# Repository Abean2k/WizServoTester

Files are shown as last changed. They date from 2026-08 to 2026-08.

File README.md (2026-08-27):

# WizServoTester



A servo controller PCB that can control up to 4 servos using onboard rotary encoders. Powered by an ESP32-C6 with two power input modes, USB and FTC 12V Battery. 

## Design and Inspo:
I wanted to solve the issue that my team and many other FTC teams I know have. When testing Gobiulda Servos (such as during Robot In 3 Days) we need a fast way to move multiple servos without using code. 
Currently, the only solution available is from Gobiulda, and the full kit for 4 servos cost about $200. So, I made WizServotester!

When designing this I made sure to keep it useful to FTC teams by allowing teams to use their existing battery to power the device. Teams already have many 12v 10 cell batteries, so I have included the xt30 connector that all these batteries have and a buck converter to step the voltage down to 5v for use in the circuit. The entire thing can be reprogrammed using the USBc and inbuilt USB programmer on the ESP32-C6. 

### Power:
This thing can be powered in two ways - USB & Battery. When under battery power all 4 servos can be used at full load and in both continuous and normal modes. However, when in USB power, only 1 servo can be used at one time. This is due to the limited power capacity of a USB C cable. Power can be selected using a switch on the pcb.  

## PCB:
I made a 2 layered PCB on Kicad for the servo tester. The pcb is around 100mm by 60mm. I have included some instructions on how to use the power switch and battery connector as well as some PCB Art (my first time trying that out <3). 

### Schematic


### PCB Layout


## Case:
This is optional, if you are recreating this project, you can choose to use my case or just not use a case. Made with two parts, a base, and a top cover type thing. Uses m3 screws to fasten the PCB into the case and the bottom of the base to the top. Designed on Onshape. 



## Firmware:
The ESP32 will run C++ with Arduino. The code is still under development. The idea is that the code can detect the voltage of the USDB to see where it's receiving power from, then it can control the servos based on the position of the rotary encoder. Lots of the code is similar to my rocketry airbrake project so V1 code development was quick. The online app that is hosted on the ESP will be added based on how the PCB performs and feedback I receive from my team about the tester. 

## Bill of Materials (BOM)

| Part | Quantity | Retailer | Total Price |
|---|---|---|---|
| ESP32-C6-WROOM-1 | 1x5 | LCSC | $21.16 |
| SMD Caps (10u, 100n, 1u, 22u) | 9 x 5 | Already have | $0.00 |
| 470u 16v Capacitor | 1x5 | LCSC | $0.61 |
| ESD9B3.3 Diode | 2x5 | LCSC | $0.53 |
| SS34 Schottky Diode | 1x5 | LCSC | $0.71 |
| SS54 Schottky Diode | 1x5 | LCSC | $0.45 |
| USB-C Receptacle | 1x5 | LCSC | $0.62 |
| XT30 Battery Connector | 1x5 | AliExpress | $2.97 |
| (01x03) Male 90 Degree Header | 4x5 | AliExpress | $5.58 |
| Resistors (10k, 5.1k, 4.7k) | 30 | Already have | $0.00 |
| EC11 Rotary Encoder | 4x5 | AliExpress | $3.24 |
| Push Button Switch | 2x5 | LCSC | $0.53 |
| SPDT Power Select Switch ($1.84) | 1x5 | LCSC | $1.84 |
| USBLC6-2SC6 (USB Protection) | 1x5 | LCSC | $0.48 |
| AMS1117-3.3 (LDO) | 1x5 | LCSC | $0.49 |
| Mini560 Buck Converter | 1x5 | AliExpress | $4.40 |
| PCB (5x boards) | 1x5 | LCSC | $11.32 |

**Taxes & Shipping: AliExpress ($0.96) + LCSC ($10.80)** 

**Total Cost For 5 PCBS: $66.69**

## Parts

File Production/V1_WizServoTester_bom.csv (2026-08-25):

Designator | Footprint | Quantity | Value | LCSC Part #
C1 | 0805 | 1 | 10u
C2, C4 | 0805 | 2 | 100n
C3 | 0805 | 1 | 1u
C5, C6, C7, C9 | 0805 | 4 | 22u
C8 | CP_Elec_8x10.5 | 1 | 470u 16v
D2 | D_SMA | 1 | SS34
D4 | D_SMA | 1 | SS54
J1 | USB_C_Receptacle_HCTL_HC-TYPE-C-16P-01A | 1 | USB_C_Receptacle_USB2.0_16P
J2 | PinHeader_1x03_P2.54mm_Horizontal | 1 | Servo_3_Header
J3 | PinHeader_1x03_P2.54mm_Horizontal | 1 | Servo_4_Header
J4 | PinHeader_1x03_P2.54mm_Horizontal | 1 | Servo_1_Header
J5 | PinHeader_1x03_P2.54mm_Horizontal | 1 | Servo_2_Header
J6 | AMASS_XT30U-F_1x02_P5.0mm_Vertical | 1 | BAT_XT30
J8 | TestPoint_2Pads_Pitch5.08mm_Drill1.3mm | 1 | BAT_Pads
R1, R4, R6 | 0805 | 3 | 10k
R2, R3 | 0805 | 2 | 5.1k
R5 | 0805 | 1 | 4.7k
SW1, SW2, SW3, SW4 | RotaryEncoder_Alps_EC11E-Switch_Vertical_H20mm_MountingHoles | 4 | EC 11
SW5, SW7 | SW_SPST_TS-1088-xR020 | 2 | SW_Push
SW6 | SW-TH_XKB_SS-12M11XX | 1 | SW_SPDT | C2879832
U1 | ESP32-C6-WROOM-1 | 1 | ESP32-C6-WROOM-1
U2 | SOT-23-6 | 1 | USBLC6-2SC6
U3 | SOT-223-3_TabPin2 | 1 | AMS1117-3.3
U4 | mini650 | 1 | Mini560

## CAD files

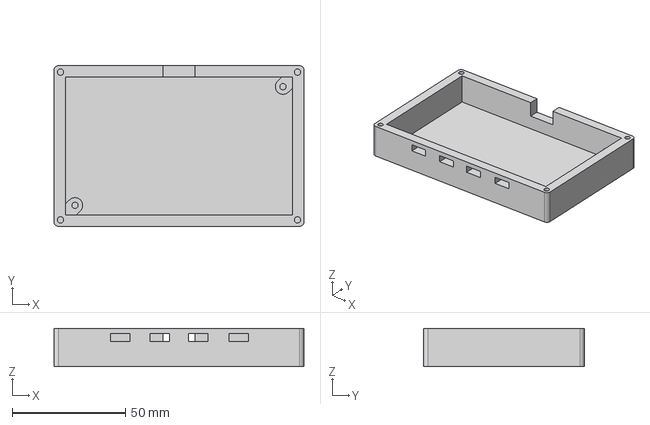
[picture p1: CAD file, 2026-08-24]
Case/Case Main.step
110.6 x 71.1 x 17.0 mm

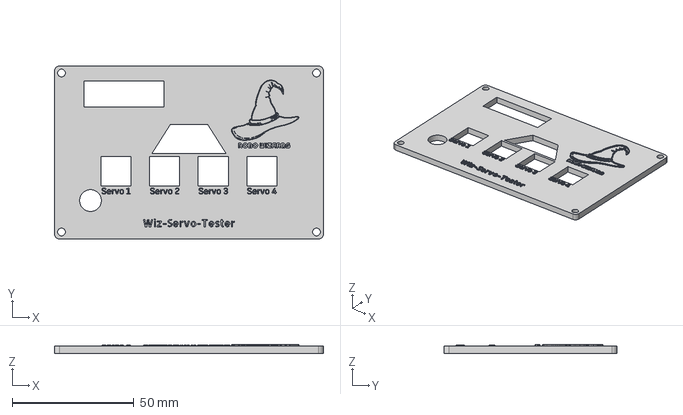
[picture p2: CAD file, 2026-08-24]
Case/Case (Top).step
110.6 x 71.1 x 3.53 mm

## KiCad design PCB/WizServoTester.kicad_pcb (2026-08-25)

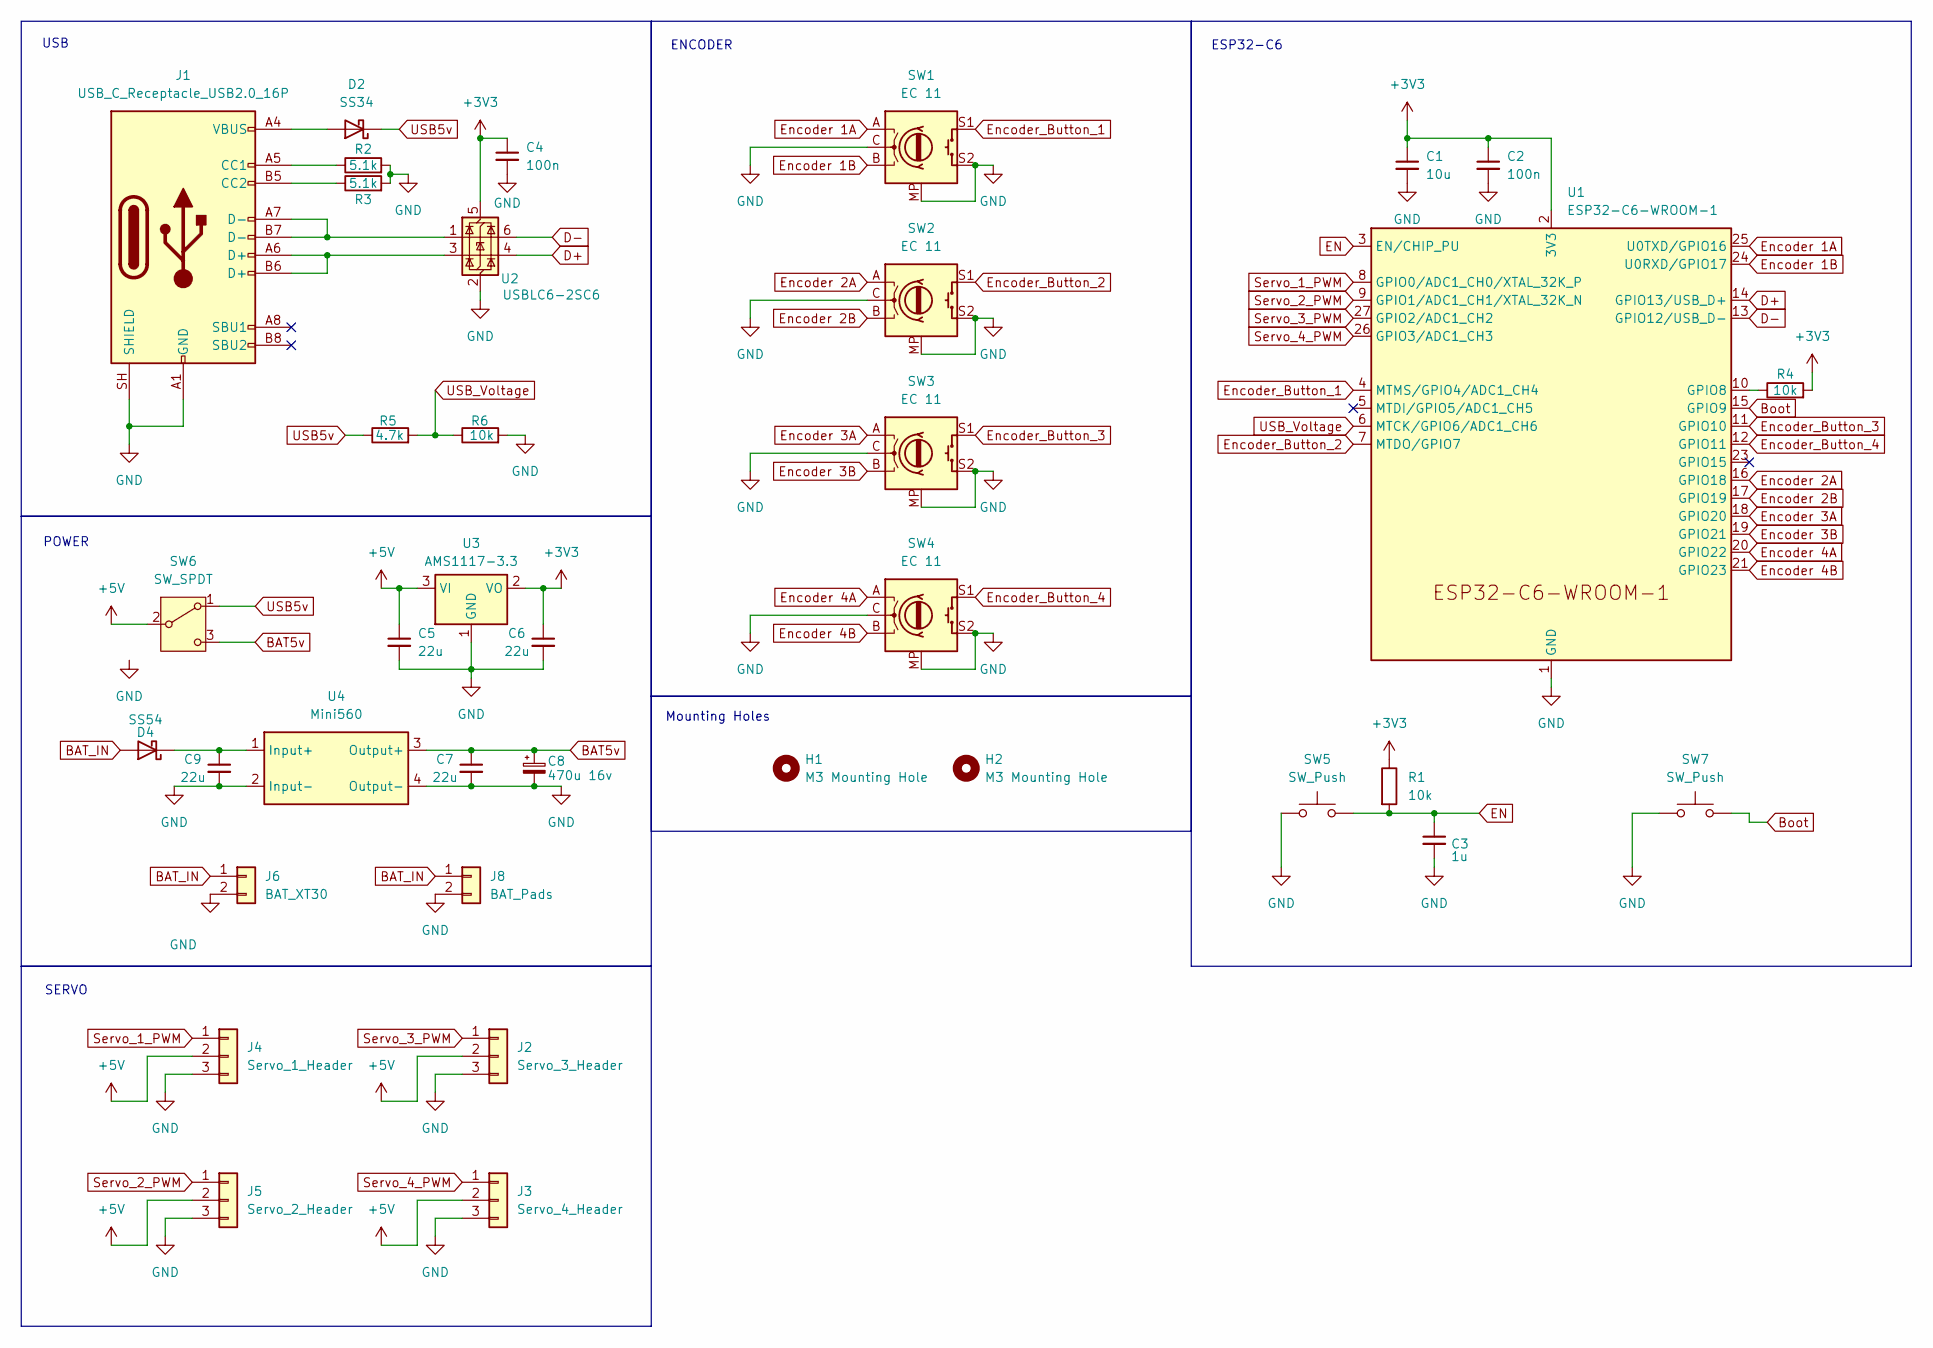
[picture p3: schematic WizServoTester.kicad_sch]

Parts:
C1: 10u; C_0805_2012Metric
C2, C4: 100n; C_0805_2012Metric
C3: 1u; C_0805_2012Metric
C5, C6, C7, C9: 22u; C_0805_2012Metric
C8: 470u 16v; CP_Elec_8x10.5
D2: SS34; D_SMA
D4: SS54; D_SMA
H1, H2: M3 Mounting Hole; MountingHole_3.2mm_M3
J1: USB_C_Receptacle_USB2.0_16P; USB_C_Receptacle_HCTL_HC-TYPE-C-16P-01A
J2: Servo_3_Header; PinHeader_1x03_P2.54mm_Horizontal
J3: Servo_4_Header; PinHeader_1x03_P2.54mm_Horizontal
J4: Servo_1_Header; PinHeader_1x03_P2.54mm_Horizontal
J5: Servo_2_Header; PinHeader_1x03_P2.54mm_Horizontal
J6: BAT_XT30; AMASS_XT30U-F_1x02_P5.0mm_Vertical
J8: BAT_Pads; TestPoint_2Pads_Pitch5.08mm_Drill1.3mm
R1, R4, R6: 10k; R_0805_2012Metric
R2, R3: 5.1k; R_0805_2012Metric
R5: 4.7k; R_0805_2012Metric
SW1, SW2, SW3, SW4: EC 11; RotaryEncoder_Alps_EC11E-Switch_Vertical_H20mm_MountingHoles
SW5, SW7: SW_Push; SW_SPST_TS-1088-xR020
SW6: SW_SPDT; SW-TH_XKB_SS-12M11XX
U1: ESP32-C6-WROOM-1
U2: USBLC6-2SC6; SOT-23-6
U3: AMS1117-3.3; SOT-223-3_TabPin2
U4: Mini560; mini650

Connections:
+3V3: C1.1, C2.1, C4.1, C6.1, R1.1, R4.2, U1.2 (3V3), U2.5 (VBUS), U3.2 (VO)
+5V: C5.1, J2.2, J3.2, J4.2, J5.2, SW6.2 (B), U3.3 (VI)
BAT5v: C7.1, C8.1, SW6.3 (C), U4.3 (Output+)
BAT_IN: D4.2 (A), J6.1, J8.1
Boot: SW7.2, U1.15 (GPIO9)
D+: U1.14 (GPIO13/USB_D+), U2.4 (I/O2)
D-: U1.13 (GPIO12/USB_D-), U2.6 (I/O1)
EN: C3.1, R1.2, SW5.2, U1.3 (EN/CHIP_PU)
Encoder 1A: SW1.A, U1.25 (U0TXD/GPIO16)
Encoder 1B: SW1.B, U1.24 (U0RXD/GPIO17)
Encoder 2A: SW2.A, U1.16 (GPIO18)
Encoder 2B: SW2.B, U1.17 (GPIO19)
Encoder 3A: SW3.A, U1.18 (GPIO20)
Encoder 3B: SW3.B, U1.19 (GPIO21)
Encoder 4A: SW4.A, U1.20 (GPIO22)
Encoder 4B: SW4.B, U1.21 (GPIO23)
Encoder_Button_1: SW1.S1, U1.4 (MTMS/GPIO4/ADC1_CH4)
Encoder_Button_2: SW2.S1, U1.7 (MTDO/GPIO7)
Encoder_Button_3: SW3.S1, U1.11 (GPIO10)
Encoder_Button_4: SW4.S1, U1.12 (GPIO11)
GND: C1.2, C2.2, C3.2, C4.2, C5.2, C6.2, C7.2, C8.2, C9.2, J1.A1 (GND), J1.A12 (GND), J1.B1 (GND), J1.B12 (GND), J1.SH (SHIELD), J2.3, J3.3, J4.3, J5.3, J6.2, J8.2, R2.2, R3.2, R6.2, SW1.C, SW1.MP, SW1.S2, SW2.C, SW2.MP, SW2.S2, SW3.C, SW3.MP, SW3.S2, SW4.C, SW4.MP, SW4.S2, SW5.1, SW7.1, U1.1 (GND), U1.28 (GND), U1.29 (GND), U2.2 (GND), U3.1 (GND), U4.2 (Input-), U4.4 (Output-)
unnamed: D2.2 (A), J1.A4 (VBUS), J1.A9 (VBUS), J1.B4 (VBUS), J1.B9 (VBUS)
unnamed: C9.1, D4.1 (K), U4.1 (Input+)
unnamed: J1.A5 (CC1), R2.1
unnamed: J1.B5 (CC2), R3.1
unnamed: J1.A6 (D+), J1.B6 (D+), U2.3 (I/O2)
unnamed: J1.A7 (D-), J1.B7 (D-), U2.1 (I/O1)
unnamed: R4.1, U1.10 (GPIO8)
Servo_1_PWM: J4.1, U1.8 (GPIO0/ADC1_CH0/XTAL_32K_P)
Servo_2_PWM: J5.1, U1.9 (GPIO1/ADC1_CH1/XTAL_32K_N)
Servo_3_PWM: J2.1, U1.27 (GPIO2/ADC1_CH2)
Servo_4_PWM: J3.1, U1.26 (GPIO3/ADC1_CH3)
USB5v: D2.1 (K), R5.1, SW6.1 (A)
USB_Voltage: R5.2, R6.1, U1.6 (MTCK/GPIO6/ADC1_CH6)

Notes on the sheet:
ESP32-C6
ENCODER
POWER
USB
SERVO
Mounting Holes

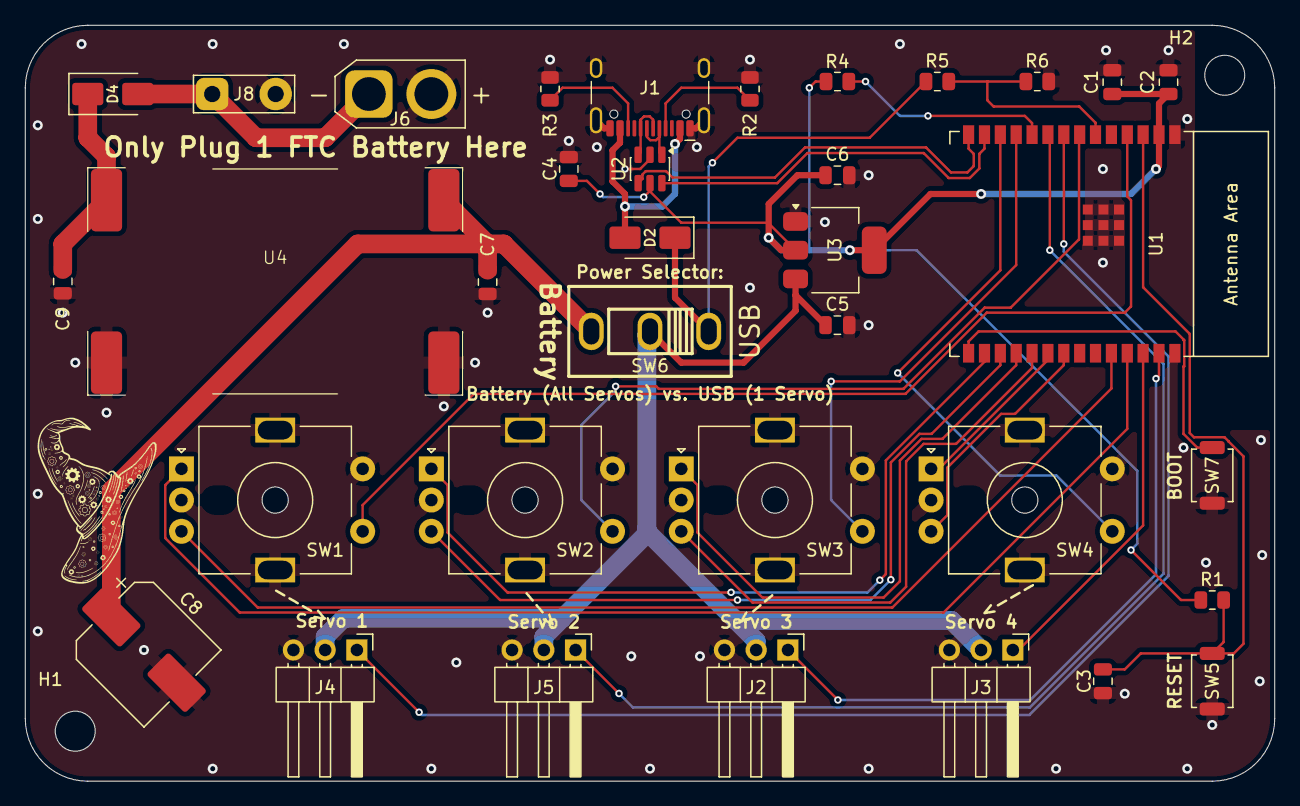
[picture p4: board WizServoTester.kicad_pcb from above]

Board: 2 copper layers, 100.0 x 60.5 mm, 37 parts (0 on the bottom side), 34 nets.

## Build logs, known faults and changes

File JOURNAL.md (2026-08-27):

---
Title: WizServotester
Github: (https://github.com/Abean2k/WizServoTester)
Description: 4-channel servo tester for FTC
Created_at: "2026-08-19"
Total Time Spent: ~16.5 Hours
---

# August 21 & August 20: <Schematic Finished>

This project is one that me, my team, and many other FTC teams I know could use and would love to have. 

***Here is the issue:*** When testing Gobiulda servos, their servo testing kit is either very expensive ($200+) and/or not compatible with the FTC batteries and all four servos. 

To solve this before Robot In 3 Days and make something that I think other robotics people might want I started working on this 4-channel servo tester. 
I wanted this to be very frictionless while we (and others) are using it. So, I decided to use the Esp32 family for my MCU, and eventually chose the C6 due to the price, GPIO pins, and ease of use. 
For control I will be having 4 encoders (one for each servo) with buttons for switching servo modes. 
For power, the tester can power one servo when connected to USB power and all 4 at the same time when connected to the battery.
To increase the usefulness for more FTC teams I am also including multiple BAT connection ports (Xt60, Powerpole, and Pads). 

Today I spent my time reading the ESP32-C6-Wroom-1 Data Sheet to see how I should set up the boot pins, where I can route each servo and encoder, etc. 
After that I started making my schematic and was able to finish it just after 12AM lol...

**Here is my Schematic:**


**Total time spent: 6h**

# August 22: <PCB Routing Finished>

Today I worked on assigning all the footprints to their respective schematics. 

While doing so I also had to make a footprint for the AliExpress buck converter thing, here was the picture of that:


After arraigning everything inside of a 100mm x 60mm pcb I routed everything. Making sure to use thick traces for the power traces. I also added the team logo at the front in the little free space.

**Total time spent: 3h**

**Here is my PCB:**


# August 23: <PCB Fixes and Case>

So today, I did a few things. Starting off, I fixed the ground planes. Before, I only had one ground plane, and the top copper plane was just a no net pad. Now, I changed both of them to ground pads and connected them with stitching vias spaced about every 15mm and I also added vias next to the doubling caps and large power gnd returns.  I also added some more logos and silkscreen stuff on the back. 

**Here are pictures of the improved pcb:**






I also made a case for the servo tester on Onshape:


**Total time spent: 4h**

# August 24: <Code and Documentation>
Today I worked on getting the project finished. I worked on the code for the servo tester. For now is to detect the voltage of the USDB to see where it's receiving power from, then it can control the servos based on the position of the rotary encoder. Many of the functions and stuff are similar to my rocketry airbrake project so the version one development of the code was quick. Once I get the servo tester made, I plan on adding more features to the code :)

I also made fixed the readme and BOM. Here are pictures of that:




**Total time spent: 3h**

# August 26: <Last PCB Fixes>
I got some suggestions to change my pcb to remove the unneeded esd diodes, and also move the large 470uF capacitor from the main 5v line to only the battery power line. 

I learned that the usb cannot have more than 10uF capacitance on it's main power rail, as that will draw way to much current from something like a computer port at startup. 

Anyway, here is the updated schematic:


**Total time spent: 0.5h**

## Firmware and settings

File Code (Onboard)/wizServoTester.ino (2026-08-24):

#include <ESP32Servo.h>

// Servo PWM pins
const int SERVO_PINS[4] = {0, 1, 2, 3};

// Rotary Encoder pins (A, B, Button)
const int ENCODER_A[4] = {16, 18, 20, 22};
const int ENCODER_B[4] = {17, 19, 21, 23};  
const int ENCODER_BUTTON[4] = {4, 7, 10, 11};

// USB Power detection (ADC pin reading USB voltage divider)
const int USB_DETECT_PIN = ADC1_CHANNEL_4; 
const int USB_THRESHOLD = 1500;  // ADC threshold for USB detection (adjust when i get pcb)

// Servo control
Servo servos[4];
const int SERVO_MIN = 1000;    // 0° position (µs)    TODO: Change based on gobiulda servo... each one is different 
const int SERVO_MAX = 2000;    // 300° position (µs)  TODO: Change based on gobiulda servo... each one is different 
const int SERVO_CENTER = 1500; // Center for continuous rotation

// Servo state (did it this way to keep it organized)
struct ServoState {
  int currentAngle;           // Current position (0-300)
  int targetAngle;            // Target position
  bool isContinuous;          // true = continuous rotation, false = normal servo
  bool isMoving;              // Currently moving to target
  int continuousSpeed;        // Speed for continuous mode (-100 to 100)
  unsigned long lastUpdate;   // For smooth movement timing
};

ServoState servoState[4] = {
  {150, 150, false, false, 0, 0},
  {150, 150, false, false, 0, 0},
  {150, 150, false, false, 0, 0},
  {150, 150, false, false, 0, 0}
};

// Encoder State
struct EncoderState {
  int lastA;
  int lastB;
  int position;  // 0-255 for servo angle mapping
  unsigned long lastButtonPress;
};

EncoderState encoderState[4] = {
  {0, 0, 128, 0},
  {0, 0, 128, 0},
  {0, 0, 128, 0},
  {0, 0, 128, 0}
};

// Power State
bool isUSBPowered = false;
int lastActiveServo = -1;  // Track which servo is currently moving (USB mode)


void setup() {
  Serial.begin(115200);
  delay(1000);
  
  Serial.println("Servo Tester Initializing...");
  
  // Setup servos
  for (int i = 0; i < 4; i++) {
    servos[i].setPeriodHertz(50);  // Standard servo frequency
    servos[i].attach(SERVO_PINS[i], SERVO_MIN, SERVO_MAX);
    servos[i].write(150);  // Center all servos
  }
  
  // Setup encoder pins
  for (int i = 0; i < 4; i++) {
    pinMode(ENCODER_A[i], INPUT_PULLUP);
    pinMode(ENCODER_B[i], INPUT_PULLUP);
    pinMode(ENCODER_BUTTON[i], INPUT_PULLUP);
    encoderState[i].lastA = digitalRead(ENCODER_A[i]);
    encoderState[i].lastB = digitalRead(ENCODER_B[i]);
  }
  
  // Setup USB detection ADC
  analogReadResolution(12);  // 12-bit resolution (0-4095)
  
  Serial.println("Setup complete!");
}

void loop() {
  // Check USB power status
  updateUSBPowerStatus();
  
  // Read all encoders
  for (int i = 0; i < 4; i++) {
    updateEncoder(i);
    updateEncoderButton(i);
  }
  
  // Update servo positions based on power mode
  if (isUSBPowered) {
    updateServosUSBMode();
  } else {
    updateServosBatteryMode();
  }
  
  // Print status (will disable when done with testing)
  static unsigned long lastPrint = 0;
  if (millis() - lastPrint > 500) {
    printStatus();
    lastPrint = millis();
  }
  
  delay(20);  // 50Hz update rate
}


void updateUSBPowerStatus() {
  int adcValue = analogRead(USB_DETECT_PIN);
  isUSBPowered = (adcValue > USB_THRESHOLD);
  
  // When switching modes, stop all servos
  static bool lastUSBState = false;
  if (isUSBPowered != lastUSBState) {
    Serial.print("Power mode changed to: ");
    Serial.println(isUSBPowered ? "USB" : "Battery");
    lastUSBState = isUSBPowered;
  }
}


void updateEncoder(int encoderNum) {
  int currentA = digitalRead(ENCODER_A[encoderNum]);
  int currentB = digitalRead(ENCODER_B[encoderNum]);
  
  // Detect rotation (quadrature encoding)
  if (currentA != encoderState[encoderNum].lastA) {
    if (currentA == currentB) {
      // Clockwise
      encoderState[encoderNum].position = constrain(
        encoderState[encoderNum].position + 5, 0, 255
      );
    } else {
      // Counter-clockwise
      encoderState[encoderNum].position = constrain(
        encoderState[encoderNum].position - 5, 0, 255
      );
    }
  }
  
  encoderState[encoderNum].lastA = currentA;
  encoderState[encoderNum].lastB = currentB;
  
  // Map encoder position (0-255) to servo angle (0-300)
  int newAngle = map(encoderState[encoderNum].position, 0, 255, 0, 300);
  
  // For normal servo mode, update target angle
  if (!servoState[encoderNum].isContinuous) {
    servoState[encoderNum].targetAngle = newAngle;
  } else {
    // For continuous mode, map to speed (-100 to 100)
    servoState[encoderNum].continuousSpeed = map(newAngle, 0, 180, -100, 100);
  }
}

void updateEncoderButton(int encoderNum) {
  if (digitalRead(ENCODER_BUTTON[encoderNum]) == LOW) {
    unsigned long now = millis();
    
    // Debounce: only register press if >200ms since last press
    if (now - encoderState[encoderNum].lastButtonPress > 200) {
      // Toggle mode
      servoState[encoderNum].isContinuous = !servoState[encoderNum].isContinuous;
      
      Serial.print("Servo ");
      Serial.print(encoderNum);
      Serial.print(" switched to ");
      Serial.println(servoState[encoderNum].isContinuous ? "Continuous" : "Normal");
      
      // Reset servo to neutral on mode switch
      if (servoState[encoderNum].isContinuous) {
        servoState[encoderNum].continuousSpeed = 0;
      } else {
        servoState[encoderNum].targetAngle = 150;
      }
      
      encoderState[encoderNum].lastButtonPress = now;
    }
  }
}

// SERVO CONTROL - USB MODE 
void updateServosUSBMode() {
  // USB mode: only 1 servo at a time
  // Priority: any continuous-mode servo running, else first normal-mode servo needing movement
  
  int servoToMove = -1;
  
  // Check if any continuous servo is running
  for (int i = 0; i < 4; i++) {
    if (servoState[i].isContinuous && servoState[i].continuousSpeed != 0) {
      servoToMove = i;
      break;
    }
  }
  
  // If no continuous servo, find first normal servo that needs movement
  if (servoToMove == -1) {
    for (int i = 0; i < 4; i++) {
      if (!servoState[i].isContinuous && servoState[i].currentAngle != servoState[i].targetAngle) {
        servoToMove = i;
        break;
      }
    }
  }
  
  // Move the selected servo
  for (int i = 0; i < 4; i++) {
    if (i == servoToMove) {
      moveServo(i);
    } else {
      // Stop other servos
      if (servoState[i].isContinuous) {
        servos[i].writeMicroseconds(SERVO_CENTER);  // Stop
      }
    }
  }
}

// ============= SERVO CONTROL - BATTERY MODE =============
void updateServosBatteryMode() {
  // Battery mode: all servos can move simultaneously
  for (int i = 0; i < 4; i++) {
    moveServo(i);
  }
}

// ============= MOVE INDIVIDUAL SERVO =============
void moveServo(int servoNum) {
  ServoState& servo = servoState[servoNum];
  
  if (servo.isContinuous) {
    // Continuous rotation mode
    if (servo.continuousSpeed == 0) {
      // Stop
      servos[servoNum].writeMicroseconds(SERVO_CENTER);
    } else if (servo.continuousSpeed > 0) {
      // Forward: speed 0-100 maps to 1500-2000 µs
      int microseconds = map(servo.continuousSpeed, 0, 100, SERVO_CENTER, SERVO_MAX);
      servos[servoNum].writeMicroseconds(microseconds);
    } else {
      // Reverse: speed -100 to 0 maps to 1000-1500 µs
      int microseconds = map(servo.continuousSpeed, -100, 0, SERVO_MIN, SERVO_CENTER);
      servos[servoNum].writeMicroseconds(microseconds);
    }
  } else {
    // Normal servo mode: smooth movement to target
    int direction = (servo.currentAngle < servo.targetAngle) ? 1 : -1;
    
    if (servo.currentAngle != servo.targetAngle) {
      servo.currentAngle += direction;
      servo.isMoving = true;
    } else {
      servo.isMoving = false;
    }
    
    // Map angle (0-300)
    int microseconds = map(servo.currentAngle, 0, 300, SERVO_MIN, SERVO_MAX);
    servos[servoNum].writeMicroseconds(microseconds);
  }
}

// printing thing (copied from rp2040 rocket thing code)
void printStatus() {
  Serial.print("Power: ");
  Serial.print(isUSBPowered ? "USB" : "Battery");
  Serial.print(" | Servos: ");
  
  for (int i = 0; i < 4; i++) {
    Serial.print("[");
    Serial.print(i);
    Serial.print(":");
    if (servoState[i].isContinuous) {
      Serial.print("C");
      Serial.print(servoState[i].continuousSpeed);
    } else {
      Serial.print("N");
      Serial.print(servoState[i].currentAngle);
    }
    Serial.print("]");
  }
  Serial.println();
}

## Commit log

2026-08-21 Finished Draft of Schematic
    [WizServoTester.kicad_pcb, WizServoTester.kicad_sch]
2026-08-21 Add project journal entry for WizServotester
    Document project details and initial progress on the 4-channel servo tester, including schematic completion and design considerations.
2026-08-22 Update JOURNAL.md with August 22 entry
    Documented progress on PCB routing and footprint assignments.
2026-08-24 Update JOURNAL with PCB improvements and case design
    Documented PCB fixes, added logos, and created a case for the servo tester.
2026-08-24 Kicad Files
    [V0.5_bom.csv, V0.5_designators.csv, V0.5_positions.csv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]
2026-08-24 Added Case and Production Files
    [Case (Top).step, Case Main.step, V1_WizServoTester_bom.csv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]
2026-08-24 Enhance README with project details and specifications
    Expanded the README with detailed project description, design inspiration, power options, PCB details, case information, firmware notes.
2026-08-25 Add Bill of Materials section to README
    Added a detailed Bill of Materials (BOM) section with parts, quantities, retailers, and prices.
2026-08-25 journal entry for August 24
    Updated journal entries with new dates and details about PCB fixes, code development, and documentation improvements.
2026-08-25 Replace schematic image in README
    Updated schematic image in README with a new image link.
2026-08-25 Pcb fixes
    [V1_WizServoTester_bom.csv, V1_WizServoTester_designators.csv, V1_WizServoTester_positions.csv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]
2026-08-27 Revise total time and PCB fix descriptions
    Updated total time spent and revised PCB notes.
2026-08-27 Replace images in README for schematic and PCB layout
    Updated schematic and PCB layout images in README.
2026-08-27 Updated Production Files
    [WizServoTester.kicad_sch]
2026-09-30 PCB Updates
    [WizServoTester.kicad_sch]
